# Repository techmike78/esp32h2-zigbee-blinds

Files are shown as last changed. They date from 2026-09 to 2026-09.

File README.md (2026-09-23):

# ESP32-H2 Zigbee Window Covering Controller

A DIY motorized window blind/curtain controller built on the **ESP32-H2**, running as a
battery-powered **Zigbee sleepy end device** with real light sleep between actions. Fully
custom firmware on pure `framework = espidf` (no Arduino layer) — designed to be paired
directly with **Zigbee2MQTT** and run for weeks/months on a 2S Li-ion pack.

## Features

- DC gear motor (DRV8870 driver) with soft speed ramp near the travel limits.
- Pulse encoder for absolute position tracking (0–100% reported to Zigbee).
- Physical buttons (UP / DOWN / SET) with single-click, long-press and combo actions
  (calibration, motor direction invert, pairing mode, factory reset).
- WS2812 status LED and buzzer feedback.
- Battery voltage monitoring (2S Li-ion) via ADC, reported as a percentage over Zigbee.
- Real ESP32-H2 light sleep (~0.1 mA measured) driven entirely by the Zigbee stack's
  `ESP_ZB_COMMON_SIGNAL_CAN_SLEEP` signal — no separate sleep timer, no polling loop.
- **Firmware updates over the air**, entirely through Zigbee (Zigbee OTA cluster) via
  Zigbee2MQTT — no physical access needed once the device is installed. See
  [`src/main.c`](src/main.c) (top-of-file comment) for the exact release process, and
  `tools/make_ota.py` / `tools/post_build_ota.py` for the packaging tooling.
- Motor tuning (min/max PWM duty, direction invert) exposed as a custom Zigbee cluster and
  editable straight from the Zigbee2MQTT UI — no reflash needed for routine tuning.

## Hardware

Custom PCB (`pcb/`, Altium project) around an ESP32-H2 module, DRV8870 motor driver, a
battery charger/2S protection circuit, and a pulse encoder tapped off the gear motor.
3D-printable enclosure and mounting parts are under `frame/` (STEP/STL). Pinout is defined at
the top of [`src/main.c`](src/main.c); the key GPIOs:

| Signal | GPIO |
|---|---|
| Motor driver IN1 / IN2 (PWM) | GPIO10 / GPIO11 |
| Pulse encoder | GPIO5 |
| Buttons UP / DOWN / SET | GPIO1 / GPIO2 / GPIO3 |
| WS2812 status LED | GPIO14 |
| Battery ADC | GPIO4 |
| Buzzer | GPIO12 |
| Load switch (LED + encoder power) | GPIO13 |

## Building and flashing

PlatformIO project, pure `framework = espidf` (ESP-IDF 5.5.x under the hood via
`pioarduino`/`platform-espressif32` — used only for ESP32-H2 board support, there is no
Arduino code in this project).

```
pio run                 # also (re)generates the OTA image under tools/ota_out/
pio run -t upload        # first flash must be by USB cable — see "First flash" below
pio device monitor
```

### First flash (one-time, by cable)

The very first firmware flashed to a device **must** be built with
`CONFIG_BOOTLOADER_APP_ROLLBACK_ENABLE=y` (already set in `sdkconfig.defaults`) — this is a
bootloader-level option and cannot itself be updated over the air. Every subsequent update can
go entirely over Zigbee OTA (see below); a bad OTA image that never rejoins the network is
rolled back automatically.

## Pairing with Zigbee2MQTT

Copy [`my_blind_controller.js`](my_blind_controller.js) into Z2M's external converters
directory and restart Z2M, then pair the device as usual. The converter exposes: cover
position/state, battery percentage/voltage, OTA support, and the custom motor-tuning
attributes (`min_pwm_duty`, `max_pwm_duty`, `motor_invert`).

**Note:** an external converter is only read from disk at Z2M startup — after editing it you
need to restart Z2M, re-running the pairing interview alone does not reload it.

## OTA updates

Full step-by-step release process (bumping the version, packaging, deploying to Z2M, rollback
behavior) is documented at the top of [`src/main.c`](src/main.c) and in
`esp32h2_light_sleep_test/roadmap.md` (Stage 21) / that project's
`.claude/skills/esp32-zigbee-idf-sleep-migration/SKILL.md` for the hardware-verified gotchas
found along the way (attribute registration crash, OTA sub-element framing, sleepy-device
delivery, etc.).

## Repository layout

- `src/main.c` — the entire firmware (single file).
- `my_blind_controller.js` — Zigbee2MQTT external converter.
- `tools/make_ota.py`, `tools/post_build_ota.py` — OTA image packaging (auto-run on build).
- `pcb/` — Altium PCB design + manufacturing outputs (Gerbers).
- `frame/` — 3D-printable enclosure/mounting parts (STEP/STL) and reference part models.
- `zigbee.csv` — flash partition table (dual-slot, sized for OTA).

## License

MIT — see [`LICENSE`](LICENSE).

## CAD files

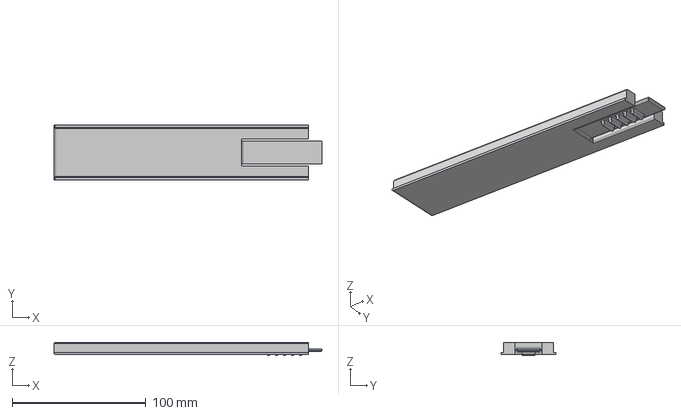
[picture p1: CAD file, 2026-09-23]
frame/крепежная планка.stp
200.0 x 41.0 x 10.0 mm

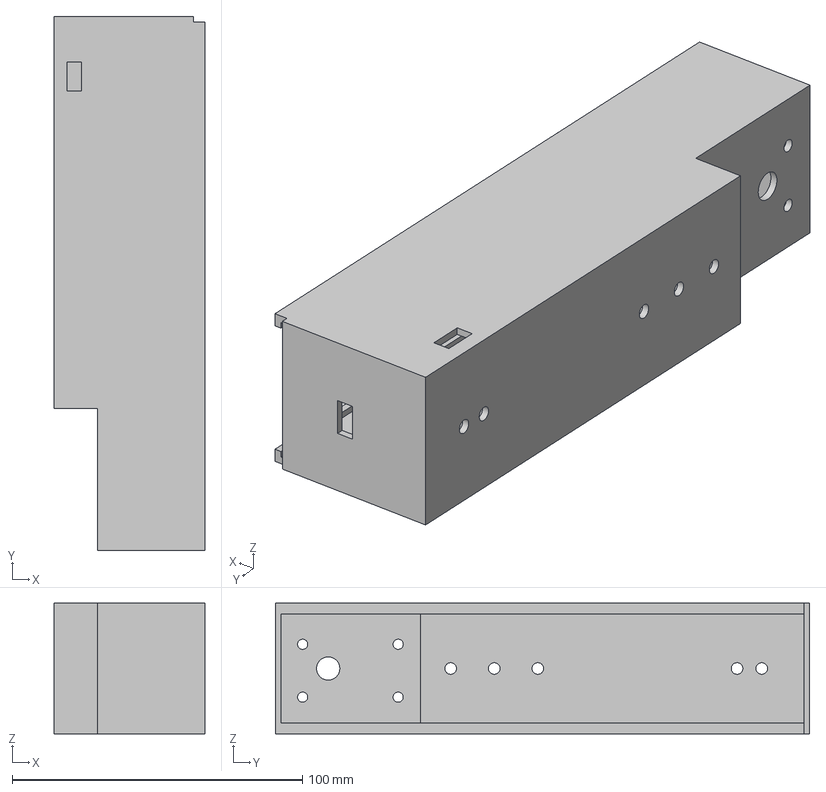
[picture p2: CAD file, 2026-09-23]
frame/корпус.stp
52.0 x 184.0 x 45.0 mm

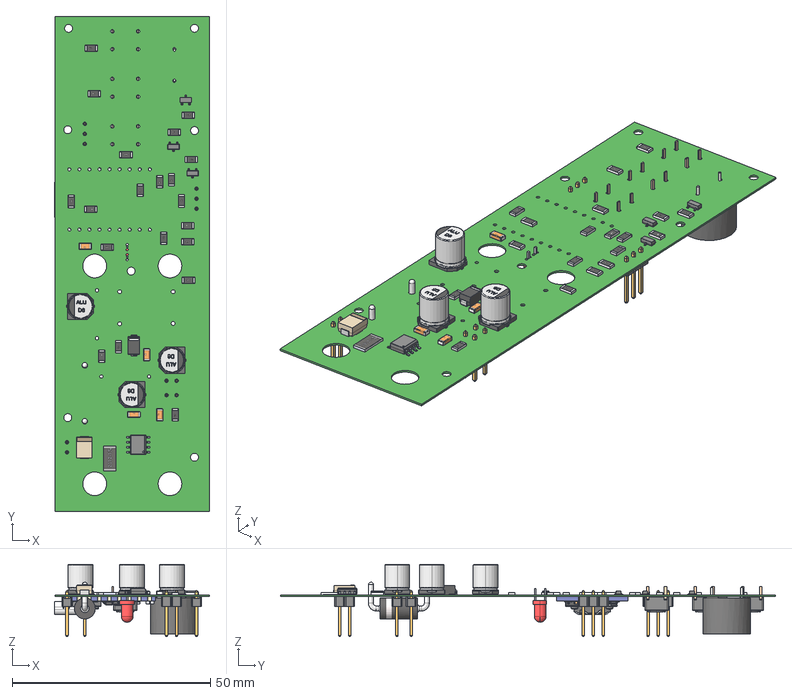
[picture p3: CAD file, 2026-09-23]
frame/esp32h2_light_sleep.step
39.2 x 125.0 x 18.2 mm
R-1206 (2) x 20
CircuitWorks-LED DIP 3MM
SW3dPS-3-lead sot23-3 x 3
HN-1x3 x 2
HN-1x2 x 3
User Library-ALU-D8_Pins_1 x 3
User Library-ALU-D8_Fuss_1 x 3
User Library-ALU-D8_K_X_F6rper_1 x 3
User Library-ALU-D8_Beschriftung_1 x 3
USB_type_C_smd_12p v1
SMD Ceramic Antenna v4 v1
Light x 2
Cathode Mark x 2
Anode Pin x 2
Cathode Pin x 2
Base x 2
3x4x2mm - 2 Pad v1 x 2
WS2812-2020 v1
RC0201 v1 x 14
Cathode
Anode
Cathode Bar
32MHZ Oscillator 2520 v3
TP4054-SOT23 v2 v1
ME6211-SOT23 v2 v1
Board
Top
Bottom
TMB12A05
Diode SMA
Buton TS-06 x 3
SMD R-2512-1%
DO-201AD
C-1206 x 4

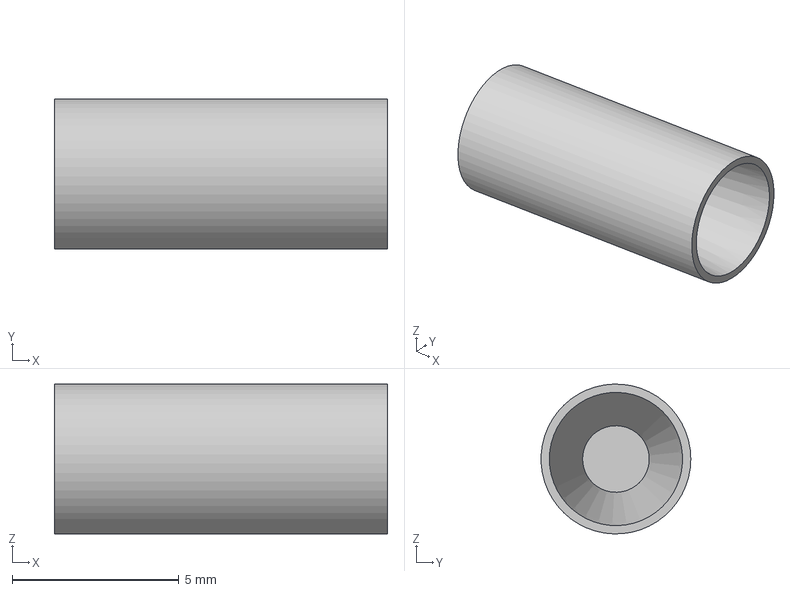
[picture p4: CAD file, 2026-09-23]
frame/button.stp
10.0 x 4.50 x 4.50 mm

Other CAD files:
pcb/esp32h2_light_sleep.DWG
frame/корпус.stl

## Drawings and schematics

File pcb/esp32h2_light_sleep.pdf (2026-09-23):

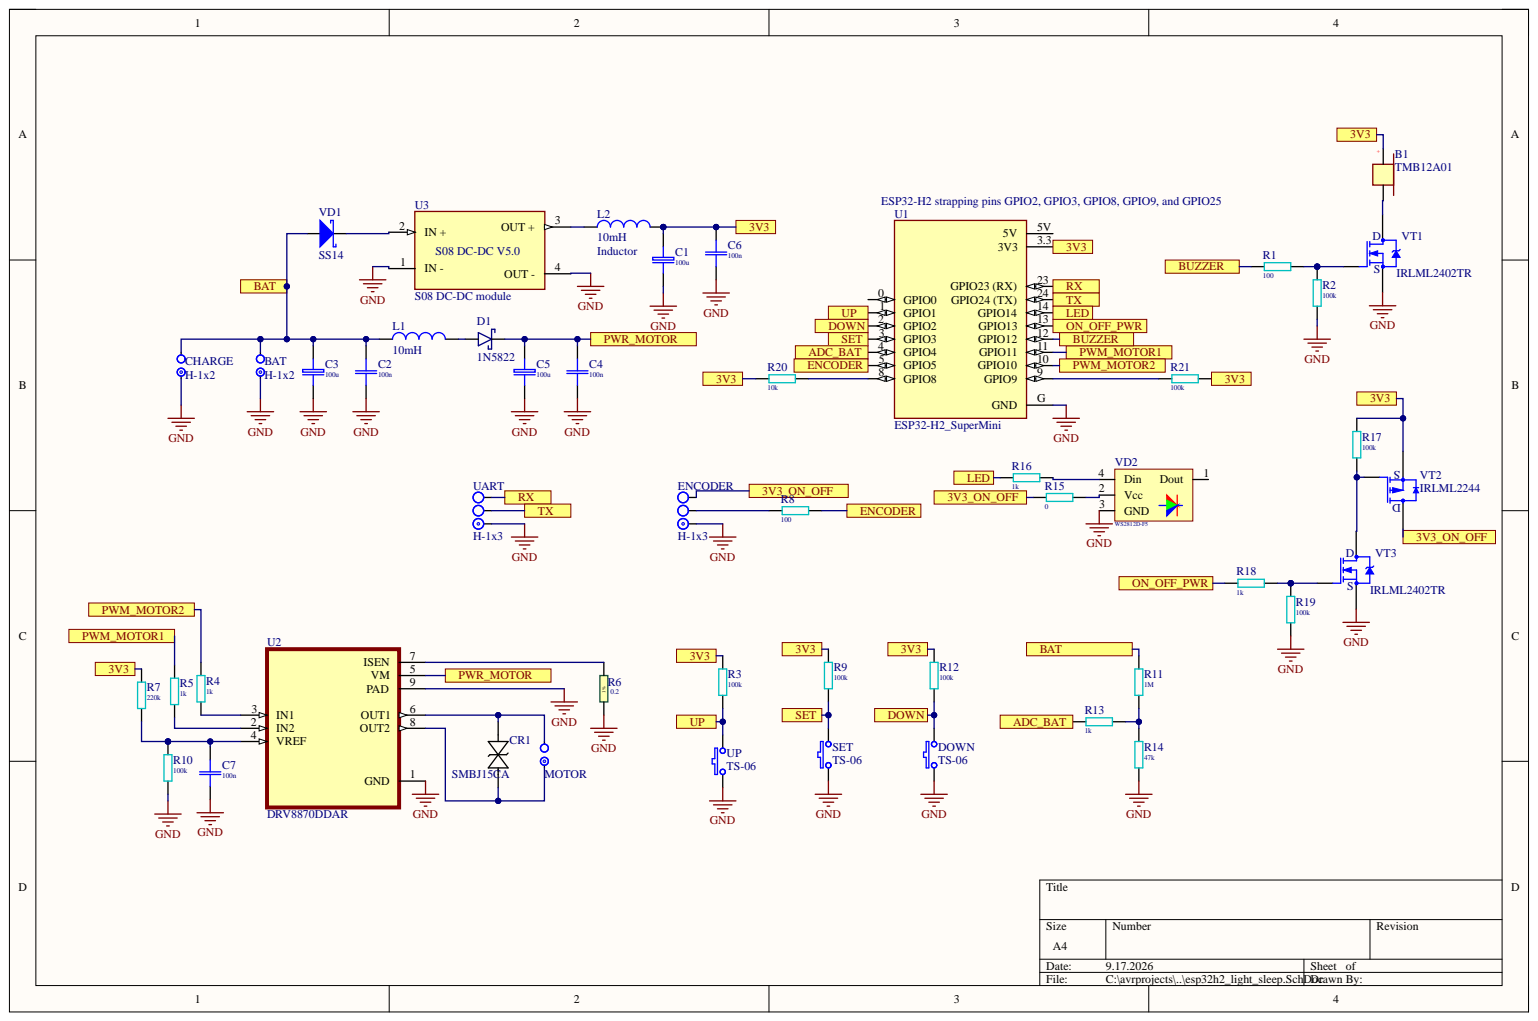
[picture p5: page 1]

ADC_BAT | PWM_MOTOR1
ENCODER | PWM_MOTOR2

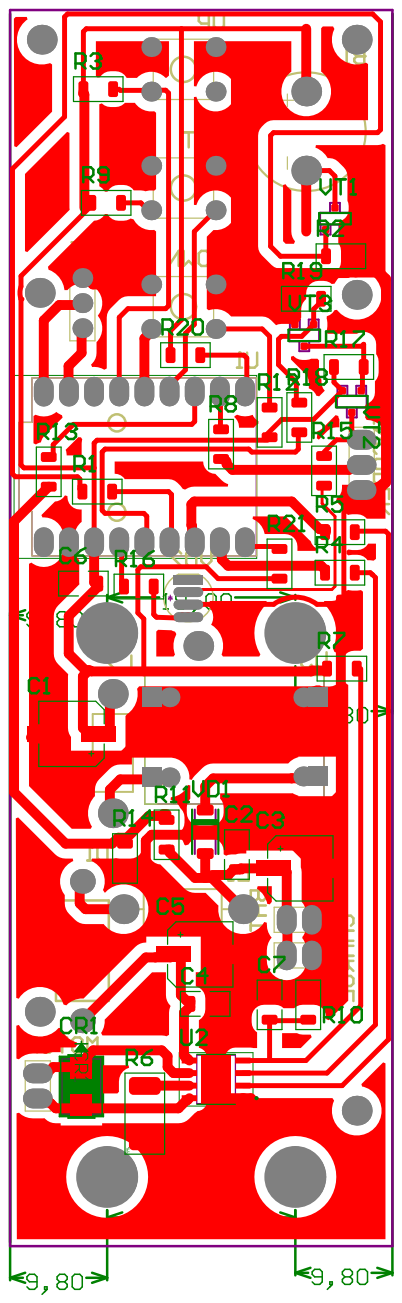
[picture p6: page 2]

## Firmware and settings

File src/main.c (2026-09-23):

/*
 * ============================================================================
 *      ESP32-H2 — Контроллер моторизованной шторы, чистый ESP-IDF
 * ============================================================================
 *
 * Полный перенос с framework=arduino на framework=espidf. Причина и вся
 * методология — см. esp32h2_light_sleep_test/roadmap.md (Этап 8-13) и
 * esp32h2_light_sleep_test/src/main.c (тот же паттерн сна, оттуда перенесён
 * практически без изменений).
 *
 * ГЛАВНОЕ АРХИТЕКТУРНОЕ ОТЛИЧИЕ ОТ Arduino-ВЕРСИИ
 * -------------------------------------------------
 * В Arduino-версии (см. git: `git show 4187ddb8:esp32h2_light_sleep/src/main.cpp`)
 * сон был на ручном таймере (`esp_light_sleep_start()` в `loop()` каждые
 * 1.5с) ОДНОВРЕМЕННО с `esp_zb_sleep_enable(true)` — два независимых
 * механизма сна, конфликтовавших друг с другом и приводивших к рассинхрону
 * `keep_alive`-опроса координатора и отвалу устройства от сети за ночь.
 * Здесь сном управляет ИСКЛЮЧИТЕЛЬНО сигнал `ESP_ZB_COMMON_SIGNAL_CAN_SLEEP`
 * в `esp_zb_app_signal_handler()` — никакого собственного таймера сна и
 * никакого `loop()` с поллингом в этом файле нет вообще.
 *
 * Реальный light sleep (0.07-0.17мА, подтверждено амперметром на тестовом
 * стенде) требует вызова `esp_pm_configure(light_sleep_enable=true)` — без
 * него автоматический tickless-idle путь никогда не выбирает
 * PM_MODE_LIGHT_SLEEP, независимо от sdkconfig-флагов (см. app_main()).
 *
 * ПЕРЕНОС LED-АВТОМАТА — НЕ ПРОВЕРЕН НА ЖЕЛЕЗЕ ДО ЭТОГО ПОРТА
 * -------------------------------------------------------------
 * Форма конечного автомата (LEDPattern/ledRefresh/ledComputeDesired) взята
 * из незакоммиченной рабочей копии Arduino-версии (не из последнего коммита
 * 4187ddb8, где ещё был старый поллинговый blinkLED()) — пользователь
 * подтвердил, что это не проверено на реальном железе, но такая форма всё
 * равно нужна: поллинг с фиксированной длительностью (delay-based blink)
 * не совместим с архитектурой сна по CAN_SLEEP (см. правило проекта про
 * поллинг в CLAUDE.md).
 *
 * НОВЫЕ ЗАВИСИМОСТИ (idf_component.yml), не угаданы — версии/API проверены
 * по официальным заголовкам/исходникам перед использованием:
 *   - espressif/button (iot_button)  — 3 физические кнопки, поддержка
 *     power-save для GPIO-кнопок.
 *   - espressif/led_strip (RMT)      — WS2812, замена Adafruit_NeoPixel.
 *
 * OTA-ОБНОВЛЕНИЕ ПО ZIGBEE (через Z2M) — как выпустить новую версию
 * -------------------------------------------------------------------
 * Устройство стоит в корпусе без доступа к USB — после первой прошивки по
 * кабелю (см. ниже) все следующие обновления идут по воздуху. Подробности,
 * найденные грабли и разбор реального обновления — roadmap.md, Этап 21,
 * и SKILL.md (раздел "Zigbee OTA").
 *
 *   1. Поднять FW_FILE_VERSION ниже (== код версии; Z2M ставит образ, только
 *      если его версия строго больше текущей на устройстве).
 *   2. `pio run` — после сборки `tools/post_build_ota.py` (extra_scripts в
 *      platformio.ini) сам пересобирает tools/ota_out/ota/<файл>.ota и
 *      tools/ota_out/my_index.json из свежего firmware.bin (номер версии,
 *      OTA_MANUFACTURER_CODE, OTA_IMAGE_TYPE читает прямо из этого файла —
 *      отдельно вызывать make_ota.py вручную не нужно).
 *   3. Скопировать оба файла (my_index.json и папку ota/) в каталог данных
 *      Z2M — туда же, где лежит его configuration.yaml (в HA-аддоне это
 *      /config/zigbee2mqtt/); "url" в индексе уже указывает на "ota/<файл>".
 *      Если ota.zigbee_ota_override_index_location в конфиге ещё не задан —
 *      задать один раз через интерфейс Z2M (Настройки -> OTA), не правкой
 *      файла на лету: работающий Z2M перезаписывает configuration.yaml из
 *      памяти и правка потеряется.
 *   4. В Z2M на карточке устройства: "Проверить обновление" -> "Обновить".
 *      Батарея должна быть заряжена (защита в ota_upgrade_handler() не
 *      начнёт приём ниже ~70%, OTA_MIN_BATTERY_VOLTAGE) — передача ~620КБ
 *      идёт по поллингу заметное время (по факту первого прогона — около
 *      двух часов) с постоянно включённым радио.
 *
 * Первая OTA-совместимая прошивка (с CONFIG_BOOTLOADER_APP_ROLLBACK_ENABLE)
 * заливается по кабелю один раз — это опция загрузчика, по воздуху себя не
 * обновляет. Неудачная OTA-прошивка (не вышла в сеть) откатывается сама
 * (esp_ota_mark_app_invalid_rollback_and_reboot() по таймеру, см.
 * OTA_VALIDATE_TIMEOUT_MS) — кабель для этого случая не нужен.
 */

#include <stdlib.h>
#include "freertos/FreeRTOS.h"
#include "freertos/task.h"
#include "driver/gpio.h"
#include "driver/ledc.h"
#include "esp_adc/adc_oneshot.h"
#include "esp_adc/adc_cali.h"
#include "esp_adc/adc_cali_scheme.h"
#include "esp_log.h"
#include "esp_check.h"
#include "esp_sleep.h"
#include "esp_pm.h"
#include "esp_rom_sys.h"
#include "esp_timer.h"
#include "esp_ota_ops.h"
#include "nvs_flash.h"
#include "nvs.h"
#include "esp_zigbee_core.h"
#include "ha/esp_zigbee_ha_standard.h"
#include "zcl/esp_zigbee_zcl_command.h"
#include "zcl/esp_zigbee_zcl_power_config.h"
#include "iot_button.h"
#include "button_gpio.h"
#include "led_strip.h"

static const char *TAG = "blinds";

// ========== НАСТРОЙКИ ОТЛАДКИ ==========
#define DEBUG_ENCODER true // true = выводить отладку энкодера

// ========== ПИНЫ ДРАЙВЕРА DRV8870 ==========
#define MOTOR_IN1_PIN GPIO_NUM_10 // ШИМ канал A (управление скоростью/направлением)
#define MOTOR_IN2_PIN GPIO_NUM_11 // ШИМ канал B (управление скоростью/направлением)

// ========== ПИН ЭНКОДЕРА ==========
#define ENCODER_PIN GPIO_NUM_5 // GPIO05 для энкодера

// ========== ПАРАМЕТРЫ ШИМ ==========
#define PWM_FREQUENCY 20000                             // 20 кГц (выше слышимого диапазона, не гудит)
#define PWM_RESOLUTION LEDC_TIMER_10_BIT                 // 10 бит (0-1023)
#define PWM_MAX_DUTY 1023        // (1<<10)-1 — аппаратный потолок скважности ШИМ

// ========== ПАРАМЕТРЫ МОТОРА ==========
// MAX/MIN_PWM_DUTY настраиваются из Z2M на лету (см. CUSTOM_SETTINGS_CLUSTER_ID) — правка на реальном
// изделии в корпусе иначе требует перезаливки по OTA (~2 часа на образ). Значения ниже — только дефолты
// на первую загрузку/если в NVS ничего не сохранено; runtime-значения — s_min_pwm_duty/s_max_pwm_duty.
#define MAX_PWM_DUTY_DEFAULT 900 // Максимальная командная скорость
#define MIN_PWM_DUTY_DEFAULT 750 // Минимальная скорость
#define TRASHHOLD_PWM_PILSE 800  // Кол-во импульсов за которые снижаем скорость

// ========== ПИНЫ КНОПОК ==========
#define BUTTON_UP_PIN GPIO_NUM_1   // Кнопка UP (замыкает на GND)
#define BUTTON_DOWN_PIN GPIO_NUM_2 // Кнопка DOWN (замыкает на GND)
#define BUTTON_SET_PIN GPIO_NUM_3  // Кнопка SET (замыкает на GND)

// ========== ПАРАМЕТРЫ КНОПОК ==========
#define LONG_PRESS_MS 3000 // Долгое нажатие 3 секунды

// ========== ПАРАМЕТРЫ ИМПУЛЬСНОГО ДАТЧИКА ==========
#define TOTAL_PULSES_LIMIT 500000 // Абсолютно максимальное количество импульсов (предел) или дефолтный предел

// ========== ПАРАМЕТРЫ СВЕТОДИОДА WS2812 ==========
#define LED_PIN GPIO_NUM_14 // Пин для WS2812
#define NUM_LEDS 1          // Количество светодиодов
#define LED_BRIGHTNESS_DIV 85 // Яркость ~3/255 из Arduino-версии — здесь делим итоговый цвет на этот коэффициент

// ========== КОНФИГУРАЦИЯ ZIGBEE ==========
#define ZIGBEE_ENDPOINT 10 // Zigbee endpoint

// ========== НАСТРОЙКИ МОТОРА, ИЗМЕНЯЕМЫЕ ИЗ Z2M (кастомный кластер) ==========
// 0xFC00 — начало приватного (manufacturer-specific range) диапазона ID кластеров по Zigbee-спеке,
// стандартный выбор для собственных кластеров у самодельных устройств (device+converter под своим
// контролем, wildcard-manufacturer-code — тот же паттерн уже видели в issues esp-zigbee-sdk). Читаются/
// пишутся как обычный ACCESS_READ_WRITE атрибут — постоянного отчёта (ACCESS_REPORTING) им не нужно.
#define CUSTOM_SETTINGS_CLUSTER_ID 0xFC00
#define ATTR_MIN_PWM_DUTY_ID 0x0000
#define ATTR_MAX_PWM_DUTY_ID 0x0001
#define ATTR_MOTOR_INVERT_ID 0x0002

// ========== OTA-ОБНОВЛЕНИЕ ПО ZIGBEE (Z2M) ==========
// Версия прошивки в формате OTA file_version — ПОВЫШАТЬ НА КАЖДЫЙ РЕЛИЗ: Z2M не ставит образ с версией <= текущей
// без force. Те же значения (FW_FILE_VERSION/OTA_MANUFACTURER_CODE/OTA_IMAGE_TYPE) нужны в tools/make_ota.py
// и в записи индекса Z2M — иначе Z2M не сопоставит образ с устройством.
#define FW_FILE_VERSION 0x00000004
#define OTA_MANUFACTURER_CODE 0x131B // = ESP_ZB_OTA_UPGRADE_MANUFACTURER_CODE_DEF_VALUE (Espressif)
#define OTA_IMAGE_TYPE 0x0001        // свой тип образа (0x0000-0xffbf — manufacturer specific)
#define OTA_HW_VERSION 0x0001
#define OTA_MAX_DATA_SIZE 64                     // размер блока данных OTA (дефолт примера esp-zigbee-sdk)
#define OTA_MIN_BATTERY_VOLTAGE 7.6f             // ~70% по batteryVoltageToPercent(); Z2M советует 70%+ для OTA батарейных устройств
#define OTA_VALIDATE_TIMEOUT_MS (10 * 60 * 1000) // не подтвердили новую прошивку за это время после загрузки — откат

#define NVS_NAMESPACE "storage"

// ========== ПЕРЕМЕННЫЕ АЦП ==========
#define ADC_BAT_PIN GPIO_NUM_4  // пин входа АЦП с делителя батареи
#define ADC_BAT_CHANNEL ADC_CHANNEL_3 // GPIO4 = ADC1_GPIO4_CHANNEL (soc/adc_channel.h, esp32h2)
#define BUZZER_PIN GPIO_NUM_12  // пин пищалки (буззера)
#define MOSFET_PIN GPIO_NUM_13  // ON_OFF_PWR по схеме: через VT3->VT2 включает линию 3V3_ON_OFF, от которой запитаны WS2812 (LED) и разъём ENCODER — не мотор (тот питается отдельно, напрямую от PWR_MOTOR)

// ========== ВРЕМЯ (замена millis()) ==========
static inline uint32_t now_ms(void)
{
    return (uint32_t)(esp_timer_get_time() / 1000);
}

// Печать аптайма в читаемом виде ч:мм:сс — для сверки момента события
// (нажатие кнопки, команда из Z2M) с многочасовым/ночным логом стабильности.
static void logUptime(const char *prefix)
{
    int64_t uptime_s = esp_timer_get_time() / 1000000;
    ESP_LOGI(TAG, "[%s] Uptime: %lld:%02lld:%02lld (h:m:s)", prefix, uptime_s / 3600, (uptime_s / 60) % 60, uptime_s % 60);
}

// ========== НАПРАВЛЕНИЕ МОТОРА / СОСТОЯНИЯ СИСТЕМЫ ==========

typedef enum {
    DIR_NONE = 0,
    DIR_OPEN = 1,
    DIR_CLOSE = 2,
} motor_direction_t;

typedef enum {
    STATE_NORMAL = 0,
    STATE_CALIBRATION = 1,
    STATE_CALIBRATION_UP = 2,
    STATE_CALIBRATION_DOWN = 3,
    STATE_PAIRING = 4,
} system_state_t;

// ========== ГЛОБАЛЬНЫЕ ПЕРЕМЕННЫЕ ==========

static motor_direction_t motor_direction = DIR_NONE;
static volatile bool motor_invert = false; // false — не инвертировано; true — инвертировано

// Runtime-настройки мотора, изменяемые из Z2M (см. CUSTOM_SETTINGS_CLUSTER_ID) без перезаливки прошивки.
// Дефолты — из #define выше, реальные значения после первого сохранения читаются из NVS в
// loadMotorSettings(). motor_invert выше персистится тем же способом, но остаётся отдельной volatile —
// её меняют ещё и из ISR-смежного контекста кнопок, тип менять не стали.
static uint16_t s_min_pwm_duty = MIN_PWM_DUTY_DEFAULT;
static uint16_t s_max_pwm_duty = MAX_PWM_DUTY_DEFAULT;

static int32_t current_pulse_position = 0;     // текущее кол-во импульсов с датчика оборотов (положение шторы)
static int32_t current_max_pulse_position = 0; // максимальное кол-во импульсов (лимит перемещения)
static int32_t target_pulse_position = 0;      // к какому кол-ву импульсов нужно двигать мотор

static int32_t calibration_pulse_position = 0; // счётчик импульсов в режиме калибровки

static volatile bool pulse_detected = false; // флаг, что в ISR обновили счётчик импульсов

static bool zigbee_connected = false;
static bool zigbee_connected_old = false;

// Длительность льготного периода после джойна — см. s_stay_awake_until_ms ниже.
// Было 20000 — на практике интервью Z2M иногда не укладывалось в это время.
#define JOIN_GRACE_PERIOD_MS 60000

// Льготный период после успешного джойна, в течение которого CAN_SLEEP
// перехватывается так же, как при !zigbee_connected — см. комментарий у
// esp_zb_app_signal_handler()/STEERING про причину (Z2M ZDO Active
// Endpoints Request проваливался с "can not get active endpoints", если
// чип успевал уйти в реальный сон раньше, чем координатор успевал
// опросить endpoint'ы/кластеры сразу после джойна).
static uint32_t s_stay_awake_until_ms = 0;

// Идёт приём OTA-образа: не даём чипу спать (перехват CAN_SLEEP, как у мотора) и не двигаем мотор.
static volatile bool s_ota_in_progress = false;

// Текущая прошивка — только что установленная по OTA и ещё не подтверждённая (ESP_OTA_IMG_PENDING_VERIFY,
// возможно только при CONFIG_BOOTLOADER_APP_ROLLBACK_ENABLE=y). Пока не подтверждена — при любом перезапуске
// загрузчик откатится на предыдущую; см. ota_confirm_new_image_if_needed().
static bool s_ota_pending_verify = false;
static esp_timer_handle_t s_ota_validate_timer = NULL;

// Не даём стеку спать, пока не подтверждён первый успешный join к сети —
// см. предупреждение про issue #787 в esp32h2_light_sleep_test/src/main.c.
static bool s_steering_done = false;

static bool motor_is_running = false;

static system_state_t system_state = STATE_NORMAL;
static float battery_voltage = 0; // напряжение на АКБ, вольт

// Таймер "быстрого поллинга" (лимиты мотора/энкодер) — тикает ТОЛЬКО пока
// мотор крутится или мы в режиме калибровки/пейринга, не постоянно. Создан
// после того, как на реальном железе подтвердилось: безусловный периодический
// esp_timer (100мс) не даёт стеку Zigbee вообще ни разу просигналить
// CAN_SLEEP — тот же класс проблемы, что и ручной poll в Arduino-loop(),
// просто через другой механизм. См. poll_timer_sync().
static esp_timer_handle_t s_motor_poll_timer = NULL;
static esp_timer_handle_t s_led_blink_timer = NULL;

// esp_zb_zcl_report_attr_cmd_req() валил стек в "Zigbee stack assertion
// failed zcl/zcl_general_commands.c:612" при каждом вызове, независимо от
// потока (Zigbee-стек, кнопка, даже esp_timer) — реальная причина оказалась
// не в контексте вызова, а в незаполненном поле .direction (см.
// report_defer_timer_cb()). Отправка всё равно оставлена отложенной через
// этот одноразовый таймер — единая точка для будущей отладки/логирования,
// лишним не мешает.
static esp_timer_handle_t s_report_defer_timer = NULL;
static volatile bool s_report_pending = false;

// Не даёт чипу входить в light sleep (ни в наш явный esp_zb_sleep_now(), ни
// в автоматический tickless idle) на время работы мотора — см. комментарий
// у initPWM()/motorSetDirectionAndSpeed(). Держится строго между
// motorStart() и motorStop(), рекурсивный (acquire/release должны быть
// сбалансированы).
static esp_pm_lock_handle_t s_motor_pm_lock = NULL;

// ========== БУЗЗЕР ==========

static void shortBeep(void)
{
    gpio_set_level(BUZZER_PIN, 1);
    vTaskDelay(pdMS_TO_TICKS(50));
    gpio_set_level(BUZZER_PIN, 0);
}

static void longBeep(void)
{
    gpio_set_level(BUZZER_PIN, 1);
    vTaskDelay(pdMS_TO_TICKS(500));
    gpio_set_level(BUZZER_PIN, 0);
}

static void doubleBeep(void)
{
    gpio_set_level(BUZZER_PIN, 1);
    vTaskDelay(pdMS_TO_TICKS(50));
    gpio_set_level(BUZZER_PIN, 0);
    vTaskDelay(pdMS_TO_TICKS(50));
    gpio_set_level(BUZZER_PIN, 1);
    vTaskDelay(pdMS_TO_TICKS(50));
    gpio_set_level(BUZZER_PIN, 0);
}

// ========== ФУНКЦИИ РАБОТЫ С ПАМЯТЬЮ (NVS) ==========

static void savePosition(void)
{
    nvs_handle_t nvs_handle;
    esp_err_t err;

    if (nvs_open(NVS_NAMESPACE, NVS_READWRITE, &nvs_handle) == ESP_OK) {
        err = nvs_set_i32(nvs_handle, "pulse_position", current_pulse_position);
        ESP_LOGI(TAG, "[NVS] set pulse_position = %s", esp_err_to_name(err));
        err = nvs_set_i32(nvs_handle, "pulse_max_count", current_max_pulse_position);
        ESP_LOGI(TAG, "[NVS] set pulse_max_count = %s", esp_err_to_name(err));
        err = nvs_commit(nvs_handle);
        ESP_LOGI(TAG, "[NVS] commit = %s", esp_err_to_name(err));
        nvs_close(nvs_handle);
        ESP_LOGI(TAG, "Position saved: %d / %d", (int)current_pulse_position, (int)current_max_pulse_position);
    } else {
        ESP_LOGW(TAG, "Position save error: %d / %d", (int)current_pulse_position, (int)current_max_pulse_position);
    }
}
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
void app_main(void)
{
    esp_err_t nvs_err = nvs_flash_init();
    if (nvs_err == ESP_ERR_NVS_NO_FREE_PAGES || nvs_err == ESP_ERR_NVS_NEW_VERSION_FOUND) {
        ESP_ERROR_CHECK(nvs_flash_erase());
        nvs_err = nvs_flash_init();
    }
    ESP_ERROR_CHECK(nvs_err);

    esp_log_level_set("zigbee", ESP_LOG_VERBOSE);
    esp_log_level_set("zboss", ESP_LOG_VERBOSE);
    esp_log_level_set("zdo", ESP_LOG_VERBOSE);

    // Версия прошивки и состояние OTA-образа. PENDING_VERIFY возможен только для образа, только что
    // установленного по OTA при CONFIG_BOOTLOADER_APP_ROLLBACK_ENABLE=y — тогда ставим таймер-предохранитель
    // (откат, если не подтвердим прошивку за OTA_VALIDATE_TIMEOUT_MS), а подтверждает её
    // ota_confirm_new_image_if_needed() после входа в сеть. Делаем ДО запуска Zigbee-задачи.
    ESP_LOGI(TAG, "Firmware file_version=0x%08x", (unsigned)FW_FILE_VERSION);
    {
        esp_ota_img_states_t ota_state;
        const esp_partition_t *running = esp_ota_get_running_partition();
        if (esp_ota_get_state_partition(running, &ota_state) == ESP_OK && ota_state == ESP_OTA_IMG_PENDING_VERIFY) {
            s_ota_pending_verify = true;
            ESP_LOGW(TAG, "[OTA] Running a NEW firmware (pending verify) — must join the network within %d ms or roll back",
                     OTA_VALIDATE_TIMEOUT_MS);
            const esp_timer_create_args_t validate_args = {
                .callback = &ota_validate_timeout_cb,
                .name = "ota_validate",
            };
            ESP_ERROR_CHECK(esp_timer_create(&validate_args, &s_ota_validate_timer));
            ESP_ERROR_CHECK(esp_timer_start_once(s_ota_validate_timer, (uint64_t)OTA_VALIDATE_TIMEOUT_MS * 1000));
        }
    }

    configure_gpio();
    setupLED();
    setLEDColor(255, 0, 0);
    vTaskDelay(pdMS_TO_TICKS(800)); // ВРЕМЕННО увеличено (было 100) для диагностики пропадающего красного
    setLEDColor(0, 255, 0);
    vTaskDelay(pdMS_TO_TICKS(800));
    setLEDColor(0, 0, 255);
    vTaskDelay(pdMS_TO_TICKS(800));
    setLEDOff();

    initPWM();
    motorSetDirectionAndSpeed(DIR_NONE, 0);

    setupButtons();
    initEncoder();
    initBatteryADC();

    loadPosition();
    loadMotorSettings();

    // Найдено чтением pm_impl.c (esp32h2_light_sleep_test/roadmap.md, Этап
    // 13): без этого вызова автоматический tickless-idle путь никогда не
    // выбирает PM_MODE_LIGHT_SLEEP, независимо от sdkconfig-флагов.
#if CONFIG_FREERTOS_USE_TICKLESS_IDLE
    esp_pm_config_t pm_config = {
        .max_freq_mhz = CONFIG_ESP_DEFAULT_CPU_FREQ_MHZ,
        .min_freq_mhz = CONFIG_ESP_DEFAULT_CPU_FREQ_MHZ,
        .light_sleep_enable = true,
    };
    ESP_ERROR_CHECK(esp_pm_configure(&pm_config));
#endif

    xTaskCreate(esp_zb_task, "Zigbee_main", 4096, NULL, 5, NULL);

    // Быстрый поллинг мотора — только СОЗДАЁМ таймер здесь, не запускаем.
    // Старт/стоп — через poll_timer_sync() из motorStart/motorStop и точек
    // смены system_state (см. их определения выше). Пока мотор не крутится
    // и мы в STATE_NORMAL, этот таймер не тикает вообще — не мешает CAN_SLEEP.
    const esp_timer_create_args_t poll_timer_args = {
        .callback = &motor_poll_timer_cb,
        .name = "motor_poll",
    };
    ESP_ERROR_CHECK(esp_timer_create(&poll_timer_args, &s_motor_poll_timer));

    // Мигание LED — та же схема: таймер только создаётся здесь, запускает/
    // останавливает его led_blink_timer_sync() из ledRefresh() в зависимости
    // от того, мигающий ли сейчас паттерн (см. её определение выше).
    const esp_timer_create_args_t led_blink_timer_args = {
        .callback = &led_blink_timer_cb,
        .name = "led_blink",
    };
    ESP_ERROR_CHECK(esp_timer_create(&led_blink_timer_args, &s_led_blink_timer));

    // Одноразовый таймер отложенной ZCL-отправки — см. report_defer_timer_cb()
    // и комментарий у s_report_defer_timer.
    const esp_timer_create_args_t report_defer_timer_args = {
        .callback = &report_defer_timer_cb,
        .name = "report_defer",
    };
    ESP_ERROR_CHECK(esp_timer_create(&report_defer_timer_args, &s_report_defer_timer));

    // Почасовой отчёт — период (1ч) на много порядков больше sleep-порога
    // (2с), сну не мешает, можно держать всегда включённым.
    const esp_timer_create_args_t hourly_timer_args = {
        .callback = &hourly_report_cb,
        .name = "hourly_report",
    };
    esp_timer_handle_t hourly_report_timer;
    ESP_ERROR_CHECK(esp_timer_create(&hourly_timer_args, &hourly_report_timer));
    ESP_ERROR_CHECK(esp_timer_start_periodic(hourly_report_timer, 3600ULL * 1000 * 1000));

    // ledRefresh() до этого места вызывается только реактивно — на смену
    // motor_is_running или на смену zigbee_connected (событие "смены" внутри
    // esp_zb_app_signal_handler()). Если стык JOIN/STEERING ни разу не
    // случился с момента загрузки (например, сеть недоступна после
    // factory reset), это событие "смены" никогда не произойдёт, и вся
    // LED-логика (паттерн, таймер мигания, MOSFET питания LED/энкодера)
    // ни разу не инициализируется — светодиод остаётся тёмным бессрочно.
    // Явный вызов здесь даёт корректное начальное состояние сразу при
    // старте, не дожидаясь первого реактивного триггера.
    ledRefresh();

    ESP_LOGI(TAG, "System Ready. Current position: %d pulses (%d%%), max=%d", (int)current_pulse_position,
             (int)pulsesToPercent(current_pulse_position), (int)current_max_pulse_position);
}

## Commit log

2026-09-23 Remove generic CAD library clutter and generated PCB output folder
    frame/: dropped ~130 Altium/DipTrace-generated 3D bodies tied to this
    board's own reference designators (R1-R21, C1-C7, U1/U2, VT1-3, etc.)
    and generic vendor component library models (SOD-123, TP4054-SOT23,
    USB-C connector, ESP32-H2 module reference, etc.) - none of it is
    project-specific or usable outside the original Altium/DipTrace
    project. Kept only the actually-authored enclosure/mounting parts
    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
    [Copy of esp32h2_light_sleep_AI.PcbDoc, Copy of esp32h2_light_sleep_AI.SchDoc, button.stp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]
2026-09-23 fix(docs): correct motor driver name DRV8871 -> DRV8870
    The chip on the board's schematic is DRV8870DDAR (VREF/ISEN pinout,
    external shunt), not DRV8871. No functional change.
    [main.c]
